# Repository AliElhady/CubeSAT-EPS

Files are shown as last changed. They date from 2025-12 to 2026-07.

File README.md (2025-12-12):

# CubeSAT-EPS
CubeSat Electrical Power System (EPS)

This project is a custom Electrical Power System for a CubeSat-class satellite, designed from scratch around a 2-cell Li-ion battery pack, solar input, and an STM32G474 microcontroller for smart power management and telemetry.

The EPS handles everything from harvesting solar energy, to charging and protecting the battery, to distributing clean, regulated rails to the rest of the satellite and streaming live power data to a ground station over LoRa.

Key Features

⚡ Solar Energy Harvesting & Battery Charging

MPPT-based solar charger (BQ24650 class) for 2S Li-ion pack
Supports simultaneous battery charging and system load powering
Automatic priority: uses solar power when available, falls back to battery when not

🔋 Battery Management & Protection

2-cell Li-ion battery pack with BMS for over-charge, over-discharge and over-current protection
Ideal-diode & reverse-polarity MOSFET circuitry on the battery input
TVS + LC filtering on critical power rails

📏 Power Monitoring & Telemetry

Multiple INA226 current/voltage monitors on battery, solar input, and main rails
Real-time telemetry sent via DL-SX1278PA LoRa module to a ground station
Designed for logging battery voltage, current, power, and solar harvesting performance

🧠 Control & Housekeeping

STM32G474RE microcontroller for EPS control, data acquisition, and LoRa communication
5 V and 3.3 V regulated rails for payload, OBC, and communication subsystems
Fault monitoring hooks for future safe-mode / load-shedding logic

🛠️ Hardware-Focused Design

KiCad-based 4-layer PCB (EPS + LoRa + sensing on a single board)
U.FL RF connector with optional π-network pads for antenna matching
Designed as a teaching/learning platform for small-sat power electronics

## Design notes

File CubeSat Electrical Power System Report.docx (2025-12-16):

CubeSat Electrical Power System (EPS) – Project Report

Ali Elhady

Gleb Matcegora

Aaron Vinod

Ilia State University

U841-Senior Design Project Conception

10/28/2025

Project Overview

Our senior design project focuses on the development of a CubeSat Electrical Power System (EPS) — a miniature version of the subsystem responsible for power generation, storage, and distribution in real satellites. The main goal is to design and implement a functional prototype that demonstrates how solar energy can be harvested, stored in rechargeable batteries, and efficiently supplied to different onboard subsystems. This mock-up will serve as a realistic educational model of a CubeSat’s power subsystem, showcasing the complete energy flow and power management principles used in small satellite missions.

The EPS prototype will consist of solar panels, a BQ24650 MPPT charge controller for optimal solar charging, 2S Li-ion battery packs for energy storage, and DC-DC converters (AP63203WU-7) providing 5 V and 3.3 V regulated outputs for different subsystems. Current and voltage monitoring sensors (INA219/INA226) will track power usage and battery status, while an STM32 microcontroller will manage data collection, control logic, and operational mode switching. The entire system will be designed and integrated using KiCad, with an emphasis on efficiency, compactness, and clarity of power flow.

At the current stage, our work primarily involves selecting compatible components, designing efficient circuit schematics, and developing the initial PCB layout. As the project progresses, we are also open to exploring additional features that could enhance the realism and functionality of the system — such as integrating an antenna for basic radio-frequency transmission, incorporating a reaction wheel for attitude control demonstrations, or implementing a low-power mode to optimize energy usage under limited sunlight conditions. These possibilities will be discussed with our supervisor before final implementation to ensure feasibility within the project’s scope.

Ultimately, the project aims to deliver a working educational prototype that demonstrates efficient energy harvesting, battery management, and power distribution in a CubeSat-like environment. This model will serve as a valuable learning platform for understanding how real satellite systems manage and distribute electrical power in space applications.

Current Progress

So far, our team has been in the brainstorming and component selection phase. We are carefully evaluating components that can work efficiently together within the limitations of size, power, and cost. This includes choosing buck converters (AP63203WU-7) for voltage regulation, Li-ion batteries for energy storage, solar panels for power input, and INA219/INA226 sensors for current and voltage monitoring. The schematic design is underway, with the circuit being transferred to KiCad for layout and preliminary simulation. This step helps visualize interconnections, verify electrical compatibility, and ensure the design remains practical for future fabrication and testing.

Future Work & Improvements

In the next phase, our team will focus on the following improvements and extensions:

1. PCB Fabrication & Testing: Finalize the KiCad design and manufacture a functional PCB prototype for laboratory testing.

2. System Optimization: Improve converter efficiency and implement dynamic power distribution using STM32 logic.

3. Telemetry & Data Logging: Add communication modules to monitor system voltage, current, and temperature remotely.

4. Reaction Wheel Integration: Design and test a reaction wheel subsystem to simulate CubeSat attitude control.

5. Final Model Assembly: Combine all modules into a compact, educational CubeSat mock-up that visually demonstrates power flow and control.

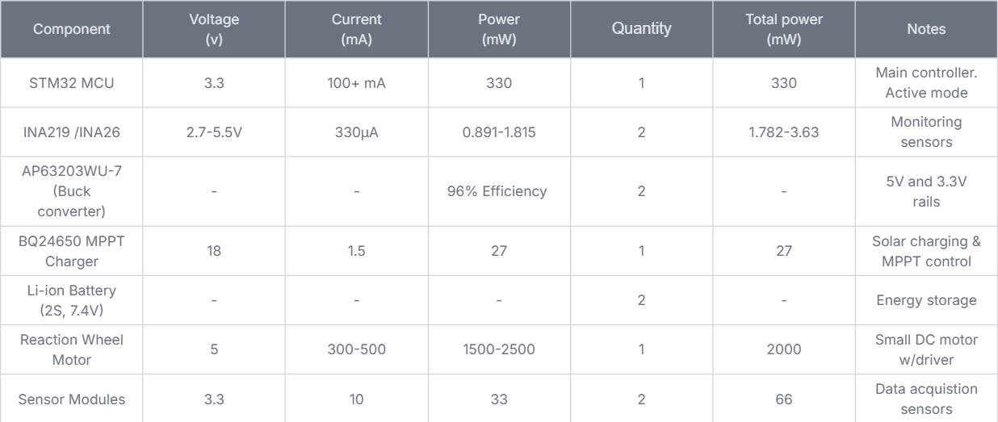
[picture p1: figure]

Power Consumption Analysis

Power Sources and Generation

Source | Voltage | Voc | Current (A) | Power (W) | Notes
Solar Panel (20-25W) | 12Nominal / 17Vmp | 21V | 1.2-1.5 | ~20-25 | Main power through mppt requires 21voc according to datasheet.
Battery Pack (2S Li-Ion, 2500 mAh or higher) | 7.4-8.4 | - | 2-4 | ~15-25 | Backup power and energy buffer

Estimated Battery Runtime

For two 3.7 V, 2500 mAh Li-ion batteries in series (≈18.5 Wh total): Idle / Light Load (0.5 W): ~37 hours With Reaction Wheel (2.5 W): ~7 hours Continuous operation during sunlight: Practically indefinite (solar-powered via MPPT).

Expected Outcomes

By the end of the project, we expect to achieve the following outcomes:

1. Functional EPS Prototype
  - A fully operational miniature Electrical Power System that can successfully harvest solar energy, charge Li-ion batteries, and regulate power output to multiple subsystems (5 V and 3.3 V rails).
  - Demonstration of real-time energy flow between solar panels, batteries, and loads.
2. Efficient Power Management
  - Implementation of a Maximum Power Point Tracking (MPPT) algorithm through the BQ24650 to maximize solar charging efficiency.
  - Stable and efficient voltage regulation using DC-DC converters (AP63203WU-7) under variable load conditions.
3. Monitoring and Control System
  - Integration of INA219/INA226 sensors with an STM32 microcontroller to measure voltage, current, and battery state-of-charge.
  - Data logging or display capability to visualize system behaviour and performance during operation.
4. Educational Demonstration Model
  - A physical prototype that visually and practically represents how a real CubeSat manages its electrical power.
  - Useful as a training and demonstration tool for future students or research in satellite power systems.
5. Design and Documentation Deliverables
  - Complete circuit schematics, PCB layout (KiCad), and a Bill of Materials (BOM).
  - A detailed project report outlining system design, operation, and performance evaluation.
6. Future Expansion Possibilities
  - While not finalized, the project may explore the possibility of integrating advanced features such as a radio-frequency antenna, a reaction wheel for orientation control, and a low-power operating mode for improved energy conservation.
  - These features, if approved, would make the prototype more representative of a complete CubeSat platform.

Summary

In summary, this project represents a comprehensive effort to design, simulate, and implement a miniature CubeSat Electrical Power System that models the real-world behavior of satellite energy management. Through careful component selection, circuit design, and microcontroller integration, the team aims to demonstrate how solar energy can be effectively captured, stored, and distributed in small-scale space systems.
The prototype will not only highlight the technical principles behind EPS design but will also serve as an educational and research tool for understanding energy flow, system reliability, and future advancements in CubeSat technology. By potentially incorporating communication and orientation features in later stages.

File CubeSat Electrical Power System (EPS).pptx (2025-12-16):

## CubeSat Electrical Power System (EPS)

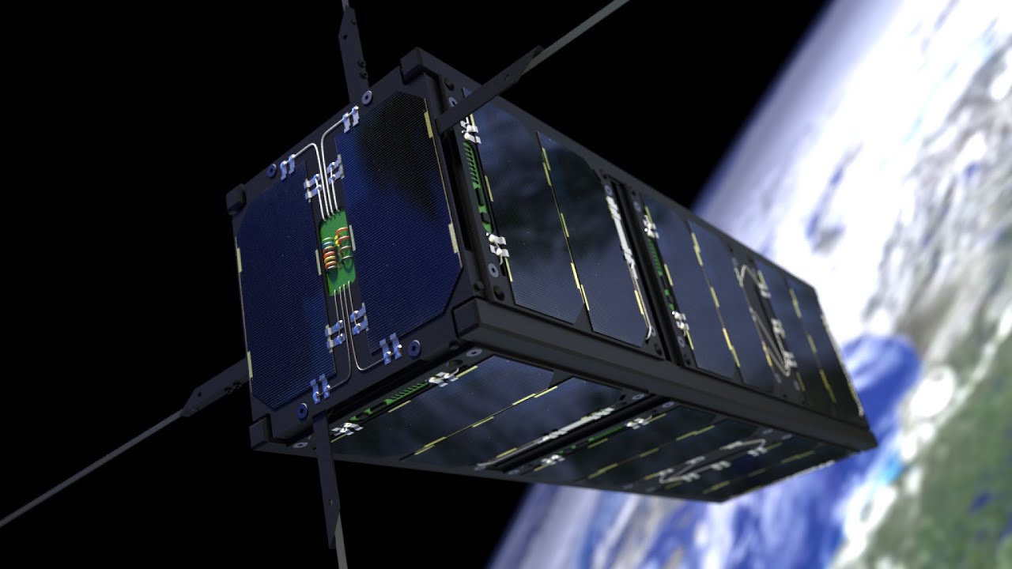
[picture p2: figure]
Picture background

## Introduction

- CubeSat Electrical Power System (EPS) manages the power collection and distribution in the satellite with an integrated Battery Management System (BMS). The EPS stores generated energy in onboard lithium-ion batteries. Some of the EPS features are:
Power generation. Solar cells, bypass diodes, and energy harvesting.
Power safety and fault protection. Polyfuses, resettable fuses, TVS diodes, Schottky diodes, isolation relays, and a watchdog timer IC.
Connectors and wiring. Board-to-board connectors, PCB terminals, a power distribution board, harnessing, connectors, screw terminals

## Project objective:

- To create a demonstration model of a CubeSat EPS to study the principles of operation of small satellite power supply systems.

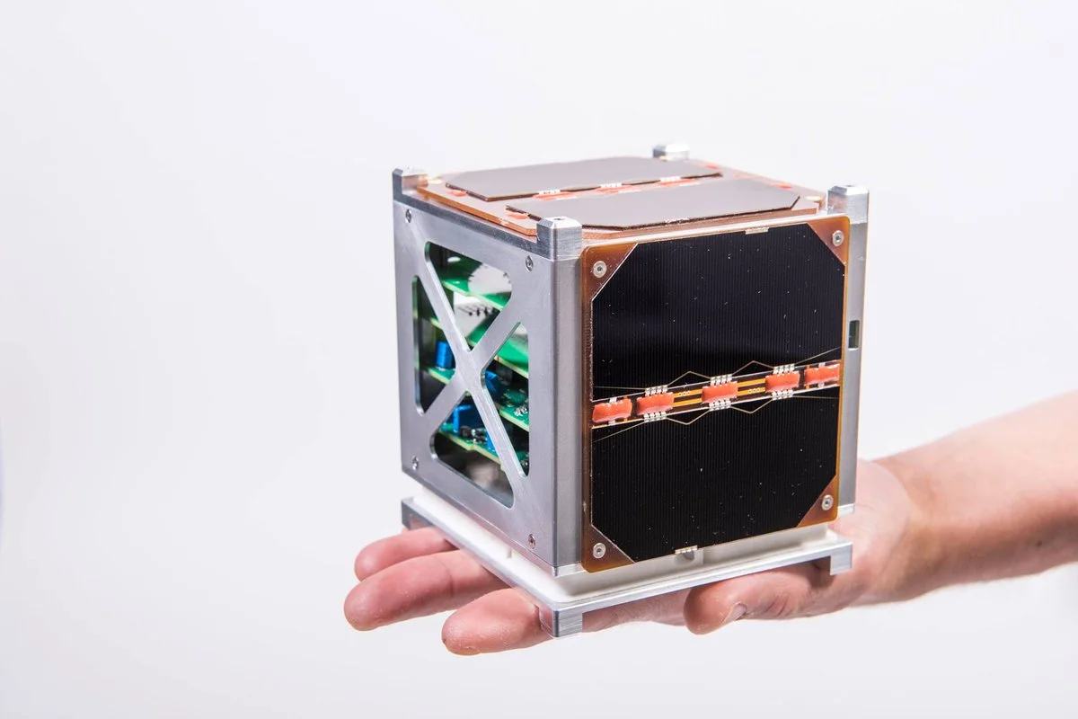
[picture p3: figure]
Picture background

## Relevance

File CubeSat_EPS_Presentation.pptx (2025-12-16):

## CubeSat Electrical Power System (EPS)

- Objective:
- To design and implement a miniature satellite power management system that simulates energy generation, storage, and distribution.
- Team Members: [Add Names]
- Supervisor: [Add Name]

## Project Overview

- CubeSats require a reliable Electrical Power System (EPS) to:
- - Generate power (via solar panels)
- - Store energy (in batteries)
- - Distribute power (through converters and controllers)
- Our mock-up replicates this using solar panel imitation, STM32 controller, and telemetry for monitoring.

## System Components

- 1. Solar Panels / Simulators
- 2. Battery (Li-ion / Li-Po) with BMS
- 3. DC-DC Converters for 5V and 3.3V
- 4. STM32 Microcontroller for control and monitoring
- 5. Load Simulation using LEDs, fans, or small modules

## System Architecture

- Power Flow:
- Solar Panel → Charge Controller → Battery → DC-DC Converters → Loads
- Control Flow:
- STM32 monitors current, voltage, state of charge, and temperature, controlling load switching & safety.

## Circuit Design

- Main Sections:
- - Charging Stage: Solar panel + TP4056 charge controller ( for battery charging )
- - Storage Stage: Battery + BMS
- - Conversion Stage: DC-DC converters
- - Measurement: Voltage dividers + INA219 or ACS712 current sensors

## STM32 Controller Functions

- - Read battery voltage and current through ADC
- - Estimate State of Charge (SOC)
- - Manage charging/discharging
- - Cut off power when voltage is too low
- - Communicate telemetry data via UART/Bluetooth

## Telemetry and Data Visualization

- Purpose: To monitor satellite power health in real time.
- Features:
- - Display battery voltage, current, and temperature
- - Live graphing of charge/discharge cycles
- - Data transmission via UART or Bluetooth

## Load Simulation

- LEDs, fans, or motors simulate subsystems.
- Controlled by MOSFETs via STM32.
- Goal: Demonstrate realistic power distribution.

## Software & Firmware Design

- Firmware (STM32):
- - ADC readings
- - Power mode logic
- - UART/Bluetooth communication
- PC Interface:
- - Serial visualization
- - Graphs and system alerts

## Expected Results

- - Stable 5V and 3.3V outputs
- - Accurate telemetry reporting
- - Automatic charge/discharge control
- - Realistic simulation of CubeSat EPS

## Future Improvements

- - Integrate MPPT
- - Add temperature compensation
- - Implement LoRa telemetry
- - Fabricate a PCB prototype

## Conclusion

- The CubeSat EPS mock-up demonstrates:
- - Efficient power management
- - Safe battery operation
- - Real-time telemetry & visualization
- Outcome: Functional miniature model of real CubeSat EPS.

## References

- - CubeSat Design Specification (Cal Poly SLO)
- - STM32 Datasheet & HAL Documentation
- - TP4056 & INA219 Datasheets
- - Research papers on CubeSat EPS design

## Q&A

- Thank you!
- Questions?

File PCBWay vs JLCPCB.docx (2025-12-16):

PCB manufacturing research – JLCPCB vs PCBWay

This report compares PCB fabrication options between JLCPCB and PCBWay for the CubeSat Electrical Power System (EPS) prototype. The goal is to identify a reliable and cost-effective manufacturer while maintaining high-quality electrical and mechanical performance.

Parameter | JLCpcb | PCBway | Notes
Base Price (4 Layers) | 7$ | 23$ | JLCPCB offers frequent 4-layer promotions for small prototypes
Base Price (2 Layers) | More expensive (via tenting adds ~20$) | Cheaper but fewer options | JLCPCB charges extra for via tenting on 2-layer boards
Size | 100 × 100 mm | 100 × 100 mm | Standard prototype board size
Quantity | 5 pcs | 5 pcs | Small prototype batch
Thickness | 1.6 mm | 1.6 mm | Standard PCB thickness
Copper weight | 1 oz (inner & outer) | 1 oz | Sufficient for low-to-medium current levels
Min Trace width | 3.5 mil (0.09 mm) | 4 mil (0.10 mm) | Higher precision allows denser routing
Solder mask | Green (default) | Green (default) | Cheapest and easiest to inspect visually
Surface Finish | ENIG (nickel and gold plated) | HASL or ENIG | ENIG is preferred for EPS: better thermal, corrosion, and electrical characteristics
Via covering | Tented (default on 4-layer | Tented or Plugged (extra cost) | 4-layer tenting included by default at JLCPCB
Build time | Standard 3-4 days | Standard 3-4 days | Expedited builds available but increase cost

Conclusion:

After careful comparison, JLCPCB is the preferred manufacturer for the CubeSat EPS prototype, it offers 4-layers PCB’s for only 7$, compared to 23$ at PCBway. JLCPCB included tented vias by default and provides reliable ENIG surface finishing, ensuring precision, corrosion resistance and superior solderability. Ideal for circuits involving

ADC readings, current monitoring and fine-pitch SMDs. PCBWay, while reputable, is significantly more expensive for equivalent builds.

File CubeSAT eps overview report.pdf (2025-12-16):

# CubeSat Electrical Power System (EPS) – Project Report

## Project Overview

Our senior design project focuses on the development of a CubeSat Electrical Power System (EPS) — a miniature version of the system that manages power generation, storage, and distribution in real satellites. The main goal is to design and implement a functional prototype that demonstrates how solar energy can be harvested, stored in rechargeable batteries, and supplied to different onboard subsystems efficiently. This mock-up will serve as a realistic educational model of a CubeSat’s power subsystem, showcasing energy flow and system management principles.

## Current Progress

So far, our team has been in the brainstorming and component selection phase. We are carefully evaluating components that can work efficiently together within the limitations of size, power, and cost. This includes choosing buck converters (AP63203WU-7) for voltage regulation, Li-ion batteries for energy storage, solar panels for power input, and INA219/INA226 sensors for current and voltage monitoring. We are also in the process of designing the circuit schematics and transferring them into KiCad for PCB layout and simulation. This step allows us to visualize the interconnections between components and determine the optimal design approach for reliability and efficiency.

## Future Plans

In the next stages, we plan to finalize the circuit design and proceed to PCB fabrication and testing. Once the power system is stable and verified, we aim to expand the project by integrating a reaction wheel system. This addition would allow us to simulate the attitude control of a real CubeSat, turning the project from a simple EPS demonstration into a complete, functional mock satellite model.

## Power Consumption Analysis

Component | Voltage (V) Current (mA)Power (mW) | Quantity Total Power (mW) | Notes
STM32 MCU | 3.3 | 100+ mA | 330 | 1 | 330 | Main controller; active mode
INA219 / INA226 | 3.3 | 330µA | 990 | | 6.6 | Monitoring sensors
| | — ≈96% efficiency | | 2 | — | 5 V and 3.3 V rails
AP63203WU-7 (Buck Converter)
—
BQ24650 MPPT Charger 12 | 15µA | 0.18 | 1 | 200 Solar charging & MPPT control
Li-Ion Battery (2S, 7.4V) | — | — | — | 2 | — | Energy storage
Reaction Wheel Motor | 5 | 300–500 | 1500–2500 | 1 | 2000 | Small DC motor w/ driver
Sensor Modules | 3.3 | 10 | 33 | 2 | 66 | Data acquisition sensors

## Power Sources and Generation

Source | Nominal Voltage | Current (A) | Power (W) | Notes
Solar Panel (25 W) | 12 | 2.08 | 25 | Main power through MPPT
Battery Pack (2S Li-Ion, 2500 mAh) | 7.4 | — | 18.5 Wh | Backup power and energy buffer

## Estimated Battery Runtime

For two 3.7 V, 2500 mAh Li-ion batteries in series (≈18.5 Wh total): Idle / Light Load (0.5 W): ~37 hours With Reaction Wheel (2.5 W): ~7 hours Continuous operation during sunlight: Practically indefinite (solar-powered via MPPT).

## Summary

The current EPS design efficiently supports the CubeSat prototype’s electronics with low power draw. The 5 V and 3.3 V rails provide flexibility for digital and electromechanical loads. The solar + battery hybrid setup ensures continuous operation even in low light. The addition of the reaction wheel will increase power demand, highlighting the need for optimized energy management and battery capacity.

## Future Work & Improvements

In the next phase, our team will focus on the following improvements and extensions: 1. PCB Fabrication & Testing: Finalize the KiCad design and manufacture a functional PCB prototype for laboratory testing. 2. System Optimization: Improve converter efficiency and implement dynamic power distribution using STM32 logic. 3. Telemetry & Data Logging: Add communication modules to monitor system voltage, current, and temperature remotely. 4. Reaction Wheel Integration: Design and test a reaction wheel subsystem to simulate CubeSat attitude control. 5. Final Model Assembly: Combine all modules into a compact, educational CubeSat mock-up that visually demonstrates power flow and control.

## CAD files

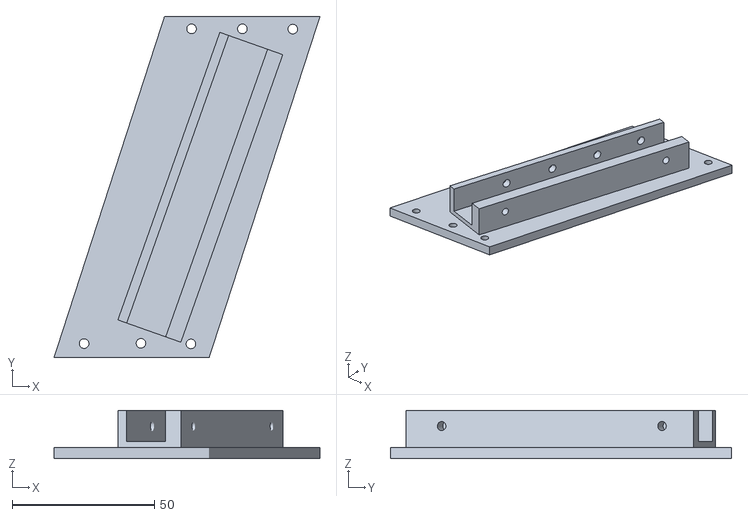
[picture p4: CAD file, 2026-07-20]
Mechanical Design/solar side1 (1).stl
93.6 x 120.0 x 17.0

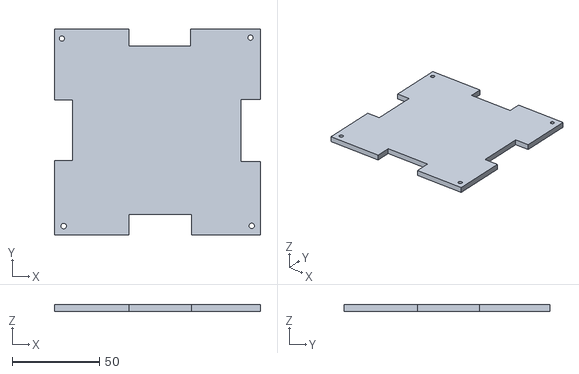
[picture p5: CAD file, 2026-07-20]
Mechanical Design/battery .stl
117.9 x 118.0 x 4.00

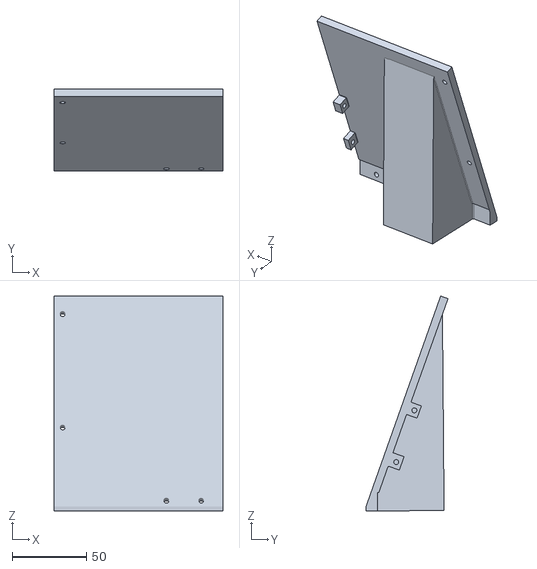
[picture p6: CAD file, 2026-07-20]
Mechanical Design/solar stand 1 (1).stl
113.8 x 55.4 x 145.1

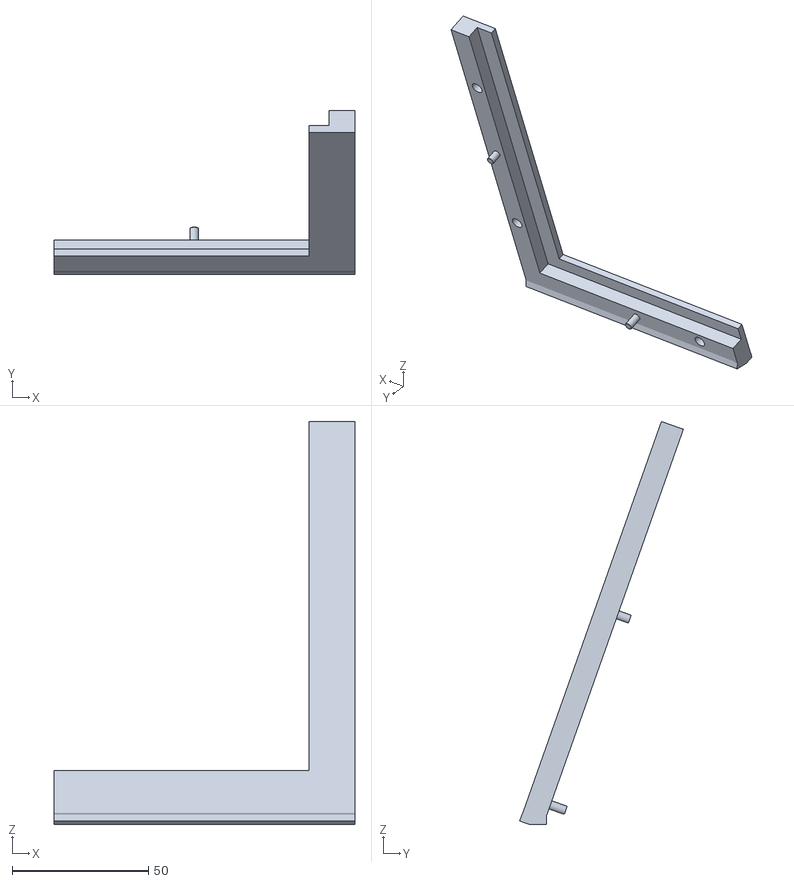
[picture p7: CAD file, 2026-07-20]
Mechanical Design/solar frame 3 (1).stl
110.4 x 60.2 x 148.0

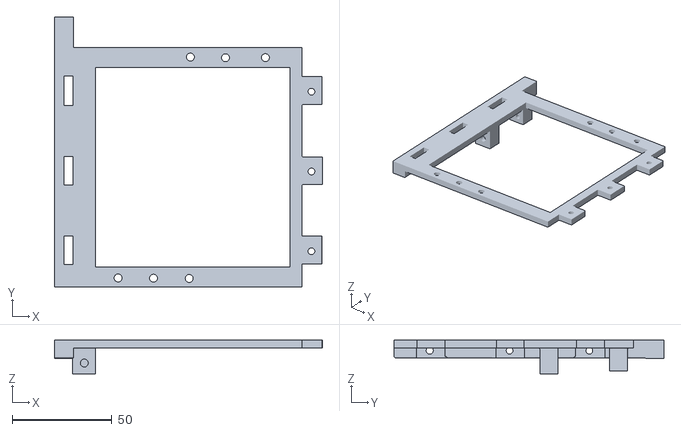
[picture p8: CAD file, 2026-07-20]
Mechanical Design/cubesat 4.stl
134.3 x 135.1 x 17.0

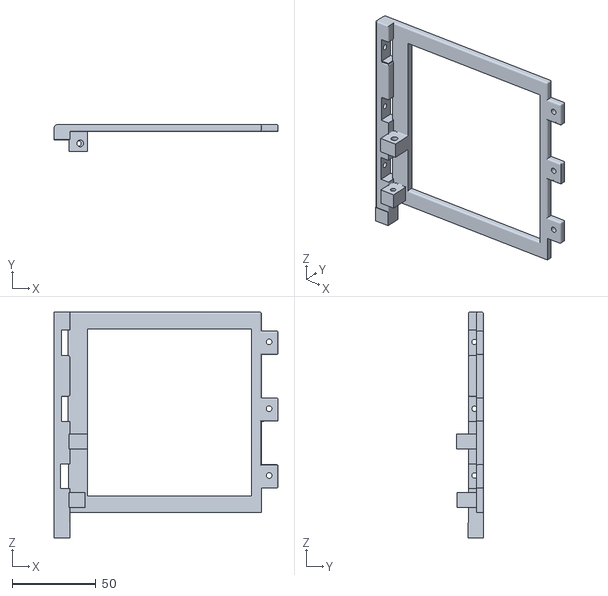
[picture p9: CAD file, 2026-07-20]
Mechanical Design/cubesat5.stl
134.1 x 16.0 x 135.1

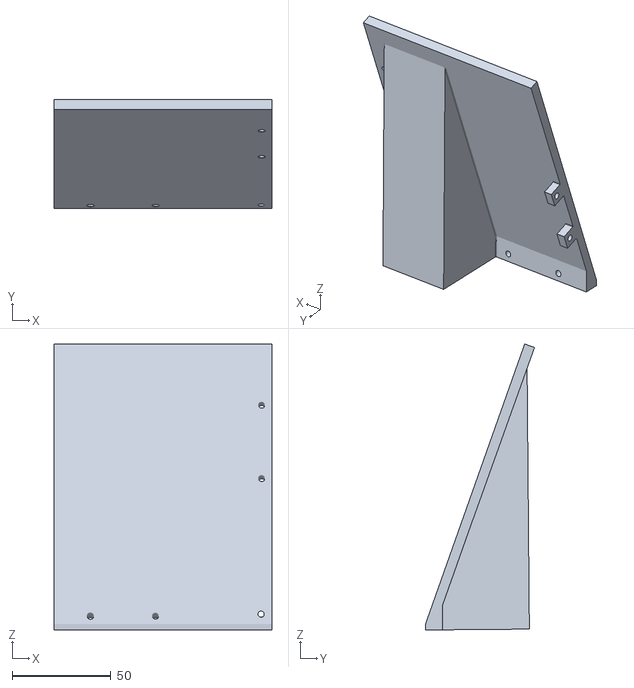
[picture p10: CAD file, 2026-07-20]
Mechanical Design/solar stand 3 (1).stl
110.4 x 55.3 x 145.1

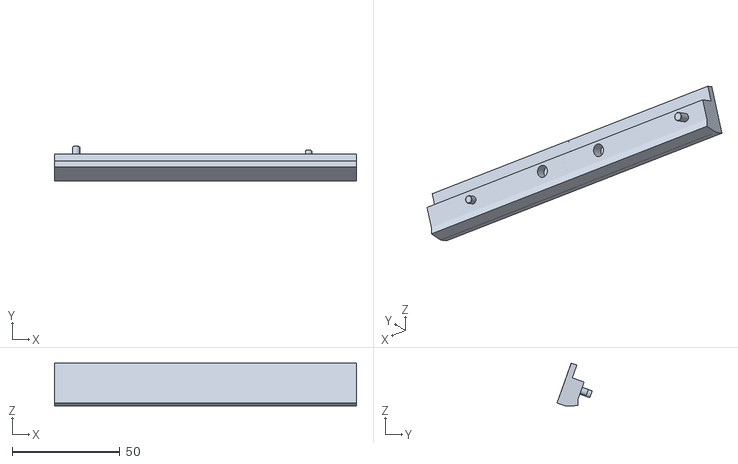
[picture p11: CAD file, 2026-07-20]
Mechanical Design/solar frame 2 (1).stl
140.4 x 16.4 x 19.9

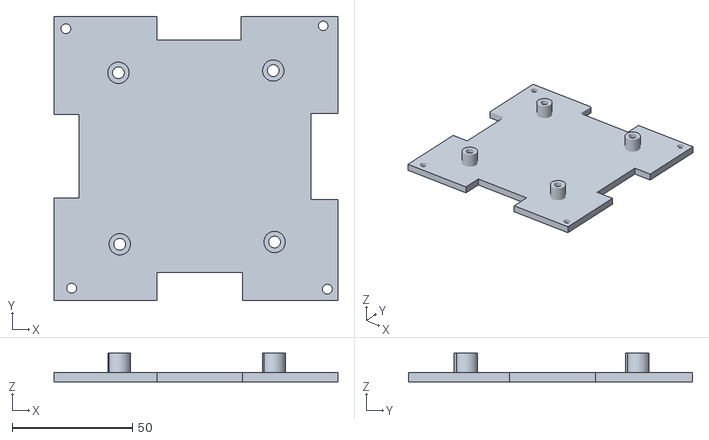
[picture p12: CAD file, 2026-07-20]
Mechanical Design/pcbstand.stl
117.9 x 118.0 x 12.0

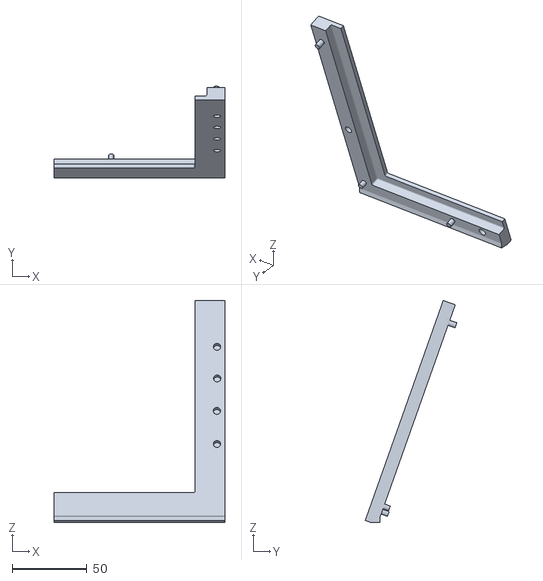
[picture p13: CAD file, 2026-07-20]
Mechanical Design/solar frame 1 left (1).stl
113.8 x 61.2 x 148.1

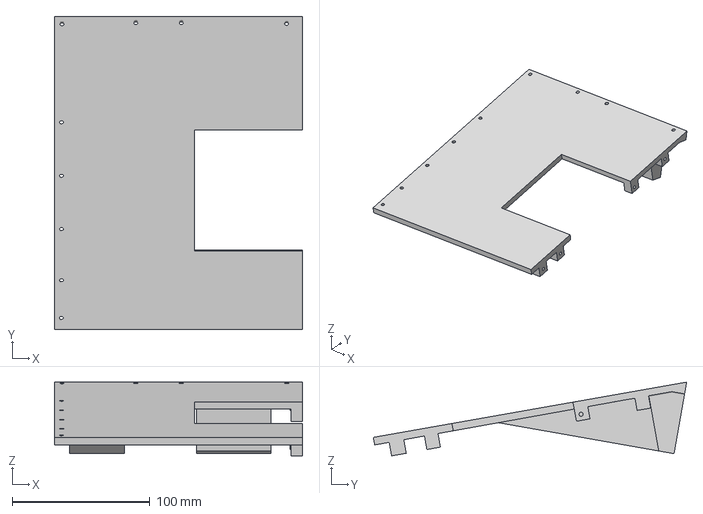
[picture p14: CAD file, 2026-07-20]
Mechanical Design/solar stand right 1 (1).3mf
179.9 x 227.3 x 53.5 mm

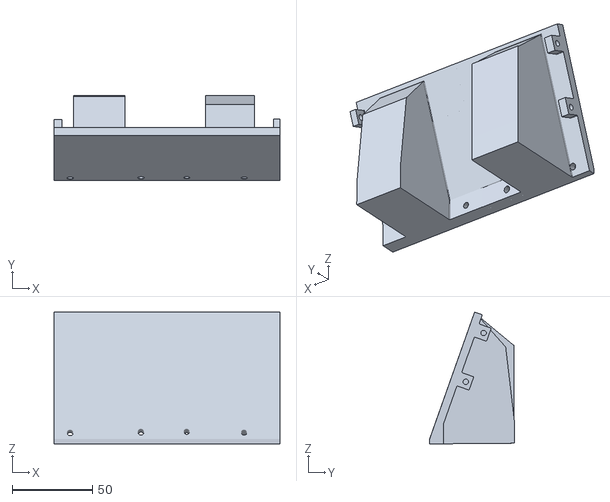
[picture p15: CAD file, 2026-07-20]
Mechanical Design/solar stand 2 (1) (1).stl
140.4 x 52.8 x 82.0

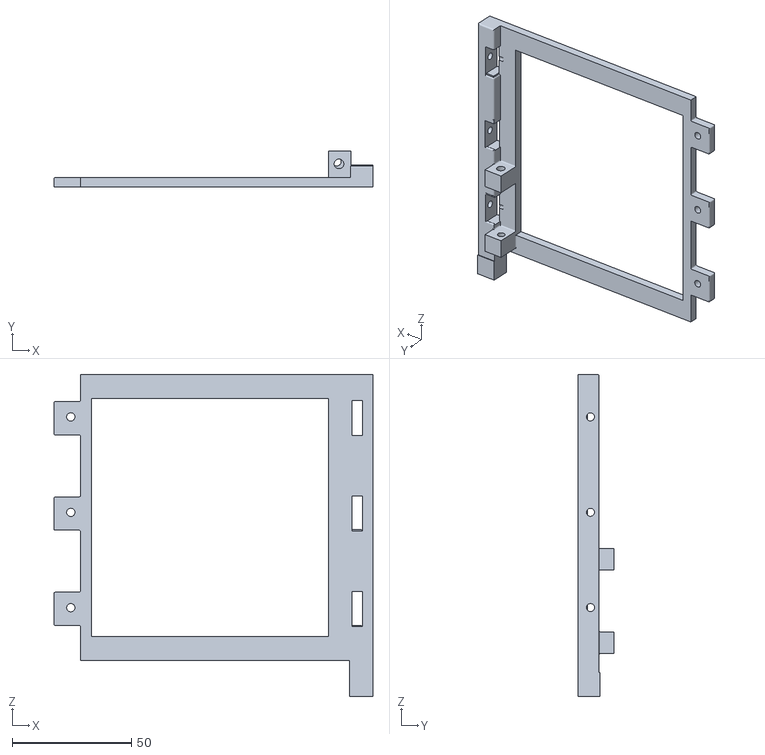
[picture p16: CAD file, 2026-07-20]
Mechanical Design/cubesat 3.stl
133.8 x 15.3 x 135.1

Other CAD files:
Mechanical Design/solar side 2 (1).stl
Mechanical Design/solar stand 1 left (1).stl
Mechanical Design/solar stand 3 left (1).stl
Mechanical Design/solar frame 1 (1).stl
Mechanical Design/solar stand 2 left (1).stl
Mechanical Design/cubesat 6.stl

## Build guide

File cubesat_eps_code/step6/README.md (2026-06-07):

# Шаг 6 — Telemetry: UART через DMA (финальная сборка)

## Файлы
- `main.c`            — точка входа
- `eps_soc.c/h`       — расчёт SOC
- `eps_fsm.c/h`       — машина состояний
- `eps_gpio.c/h`      — управление нагрузками
- `eps_flash.c/h`     — Flash persistence
- `eps_telemetry.c/h` — телеметрия UART

## Что добавилось
Передача по DMA — MCU не блокируется во время отправки.
Два режима: ASCII (отладка) и бинарный 16-байт пакет (OBC).
Адаптивный интервал: 5 с в Normal, 10 с в LowPower, 30 с в Critical.
Telem_SendNow() в каждом Enter_X() — мгновенное уведомление при смене состояния.

## Что настроить в CubeMX
- USART1 + DMA (Memory to Peripheral) → терминал/наземная станция
- USART2 + DMA → OBC
- TIM6 период = 1000 мс → Telem_TickSecond()
- ВАЖНО: MX_DMA_Init() вызывать ДО MX_USART_Init()

## Режим вывода
Переключается одной строкой в eps_telemetry.c:
  #define TELEM_MODE_ASCII    ← отладка
  #define TELEM_MODE_BINARY   ← реальный полёт

## Критерий готовности
- Пакеты приходят каждые 5 с в Normal, 30 с в Critical
- При смене состояния — пакет немедленно
- Счётчик packet_id без пропусков на 100 пакетах
- DMA: FSM продолжает работать во время передачи

## Формат ASCII пакета
```
$EPS,042,NORMAL,78%,7.85V,8.12V,COLD,ch1=1,ch2=1,chg=1,up=3600
```

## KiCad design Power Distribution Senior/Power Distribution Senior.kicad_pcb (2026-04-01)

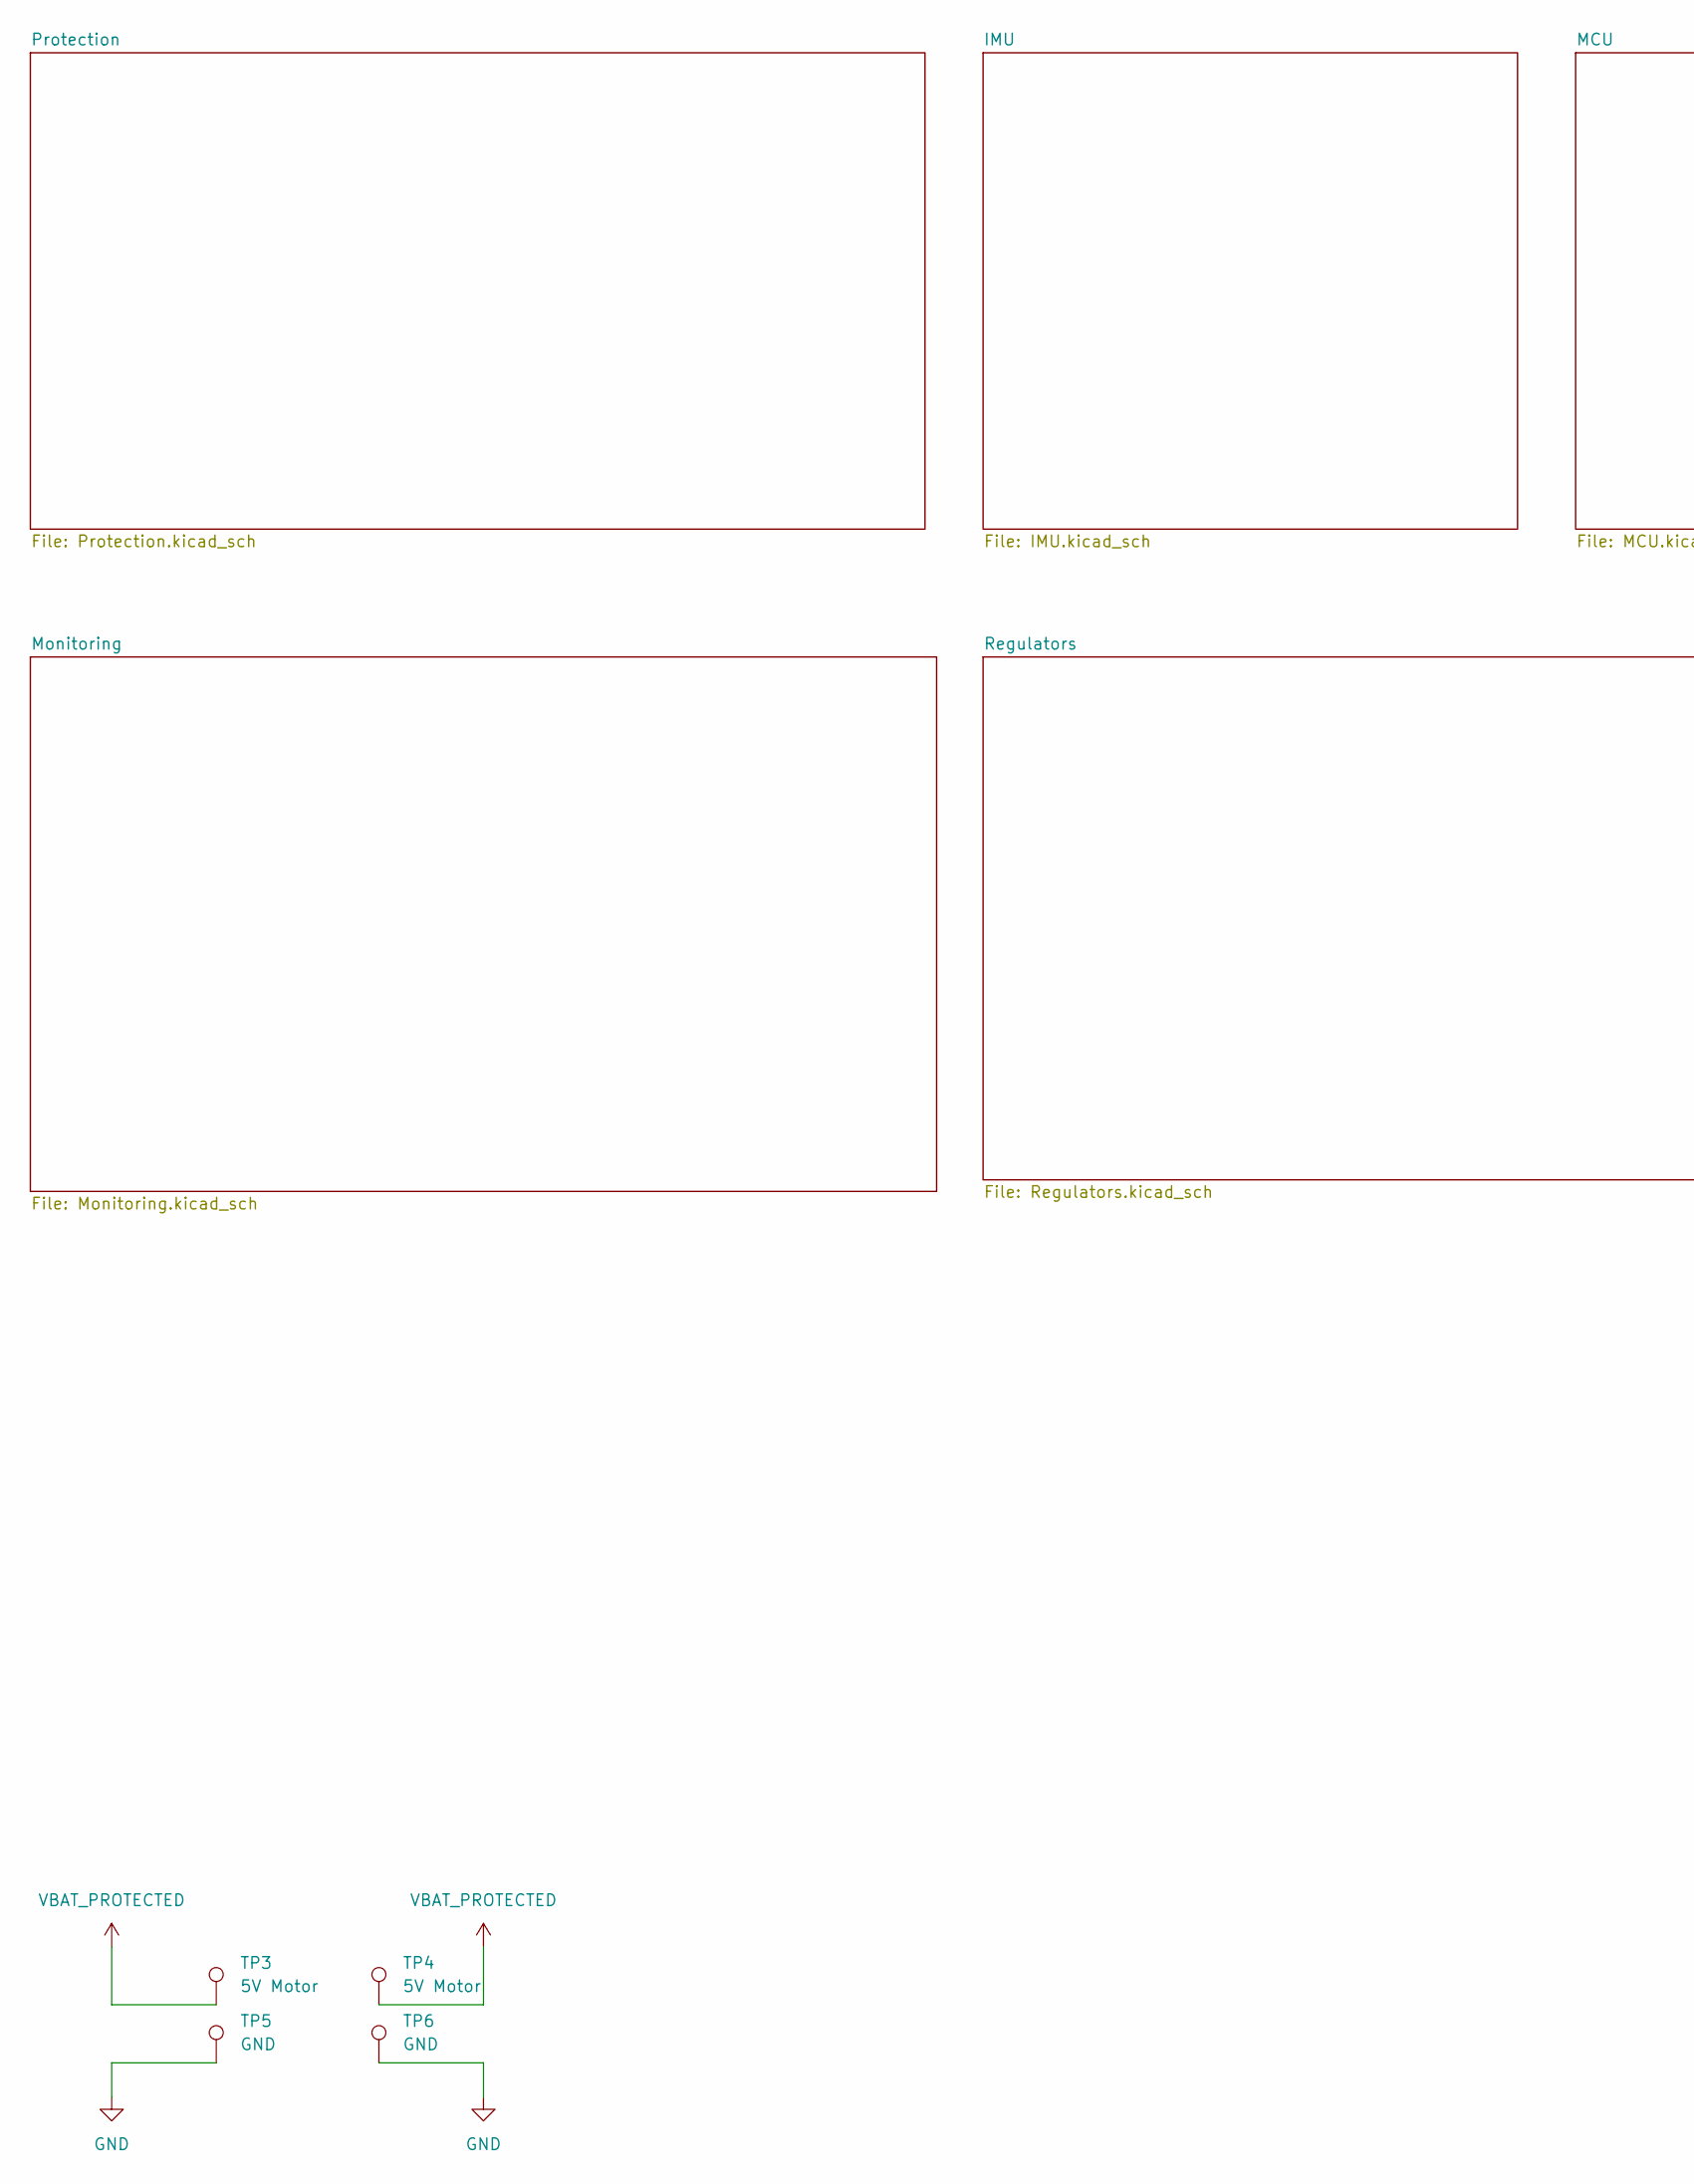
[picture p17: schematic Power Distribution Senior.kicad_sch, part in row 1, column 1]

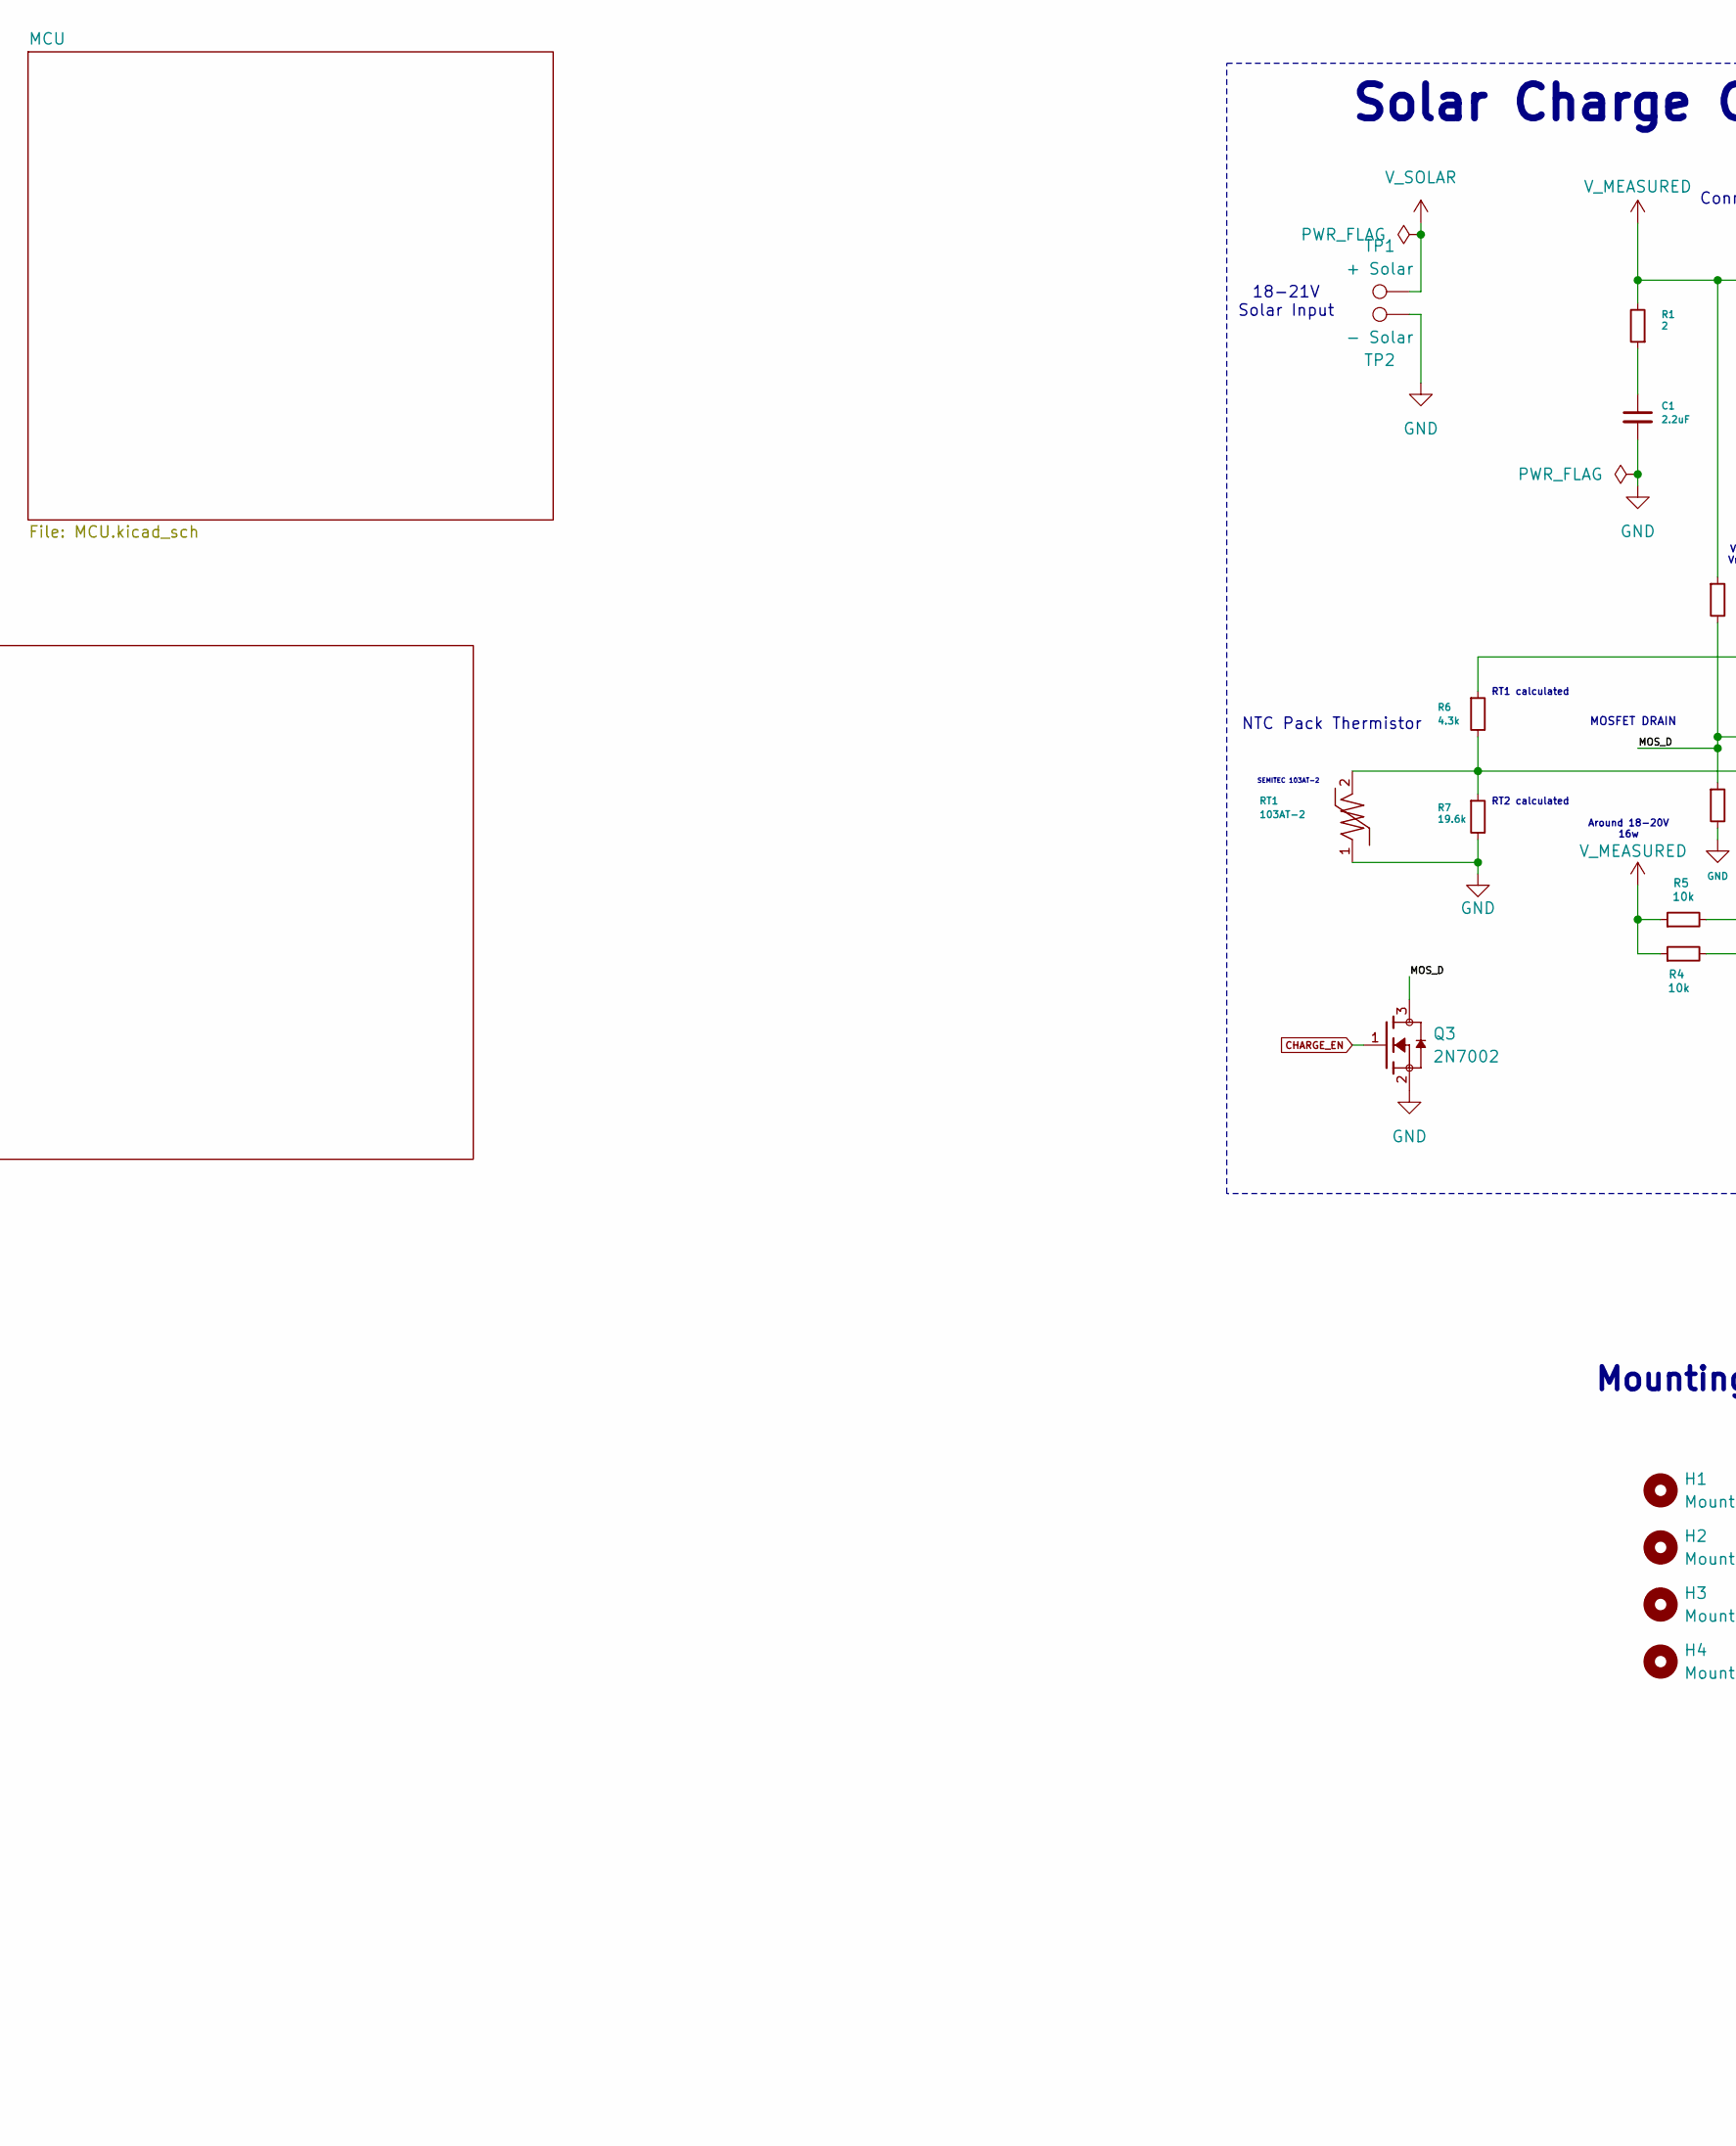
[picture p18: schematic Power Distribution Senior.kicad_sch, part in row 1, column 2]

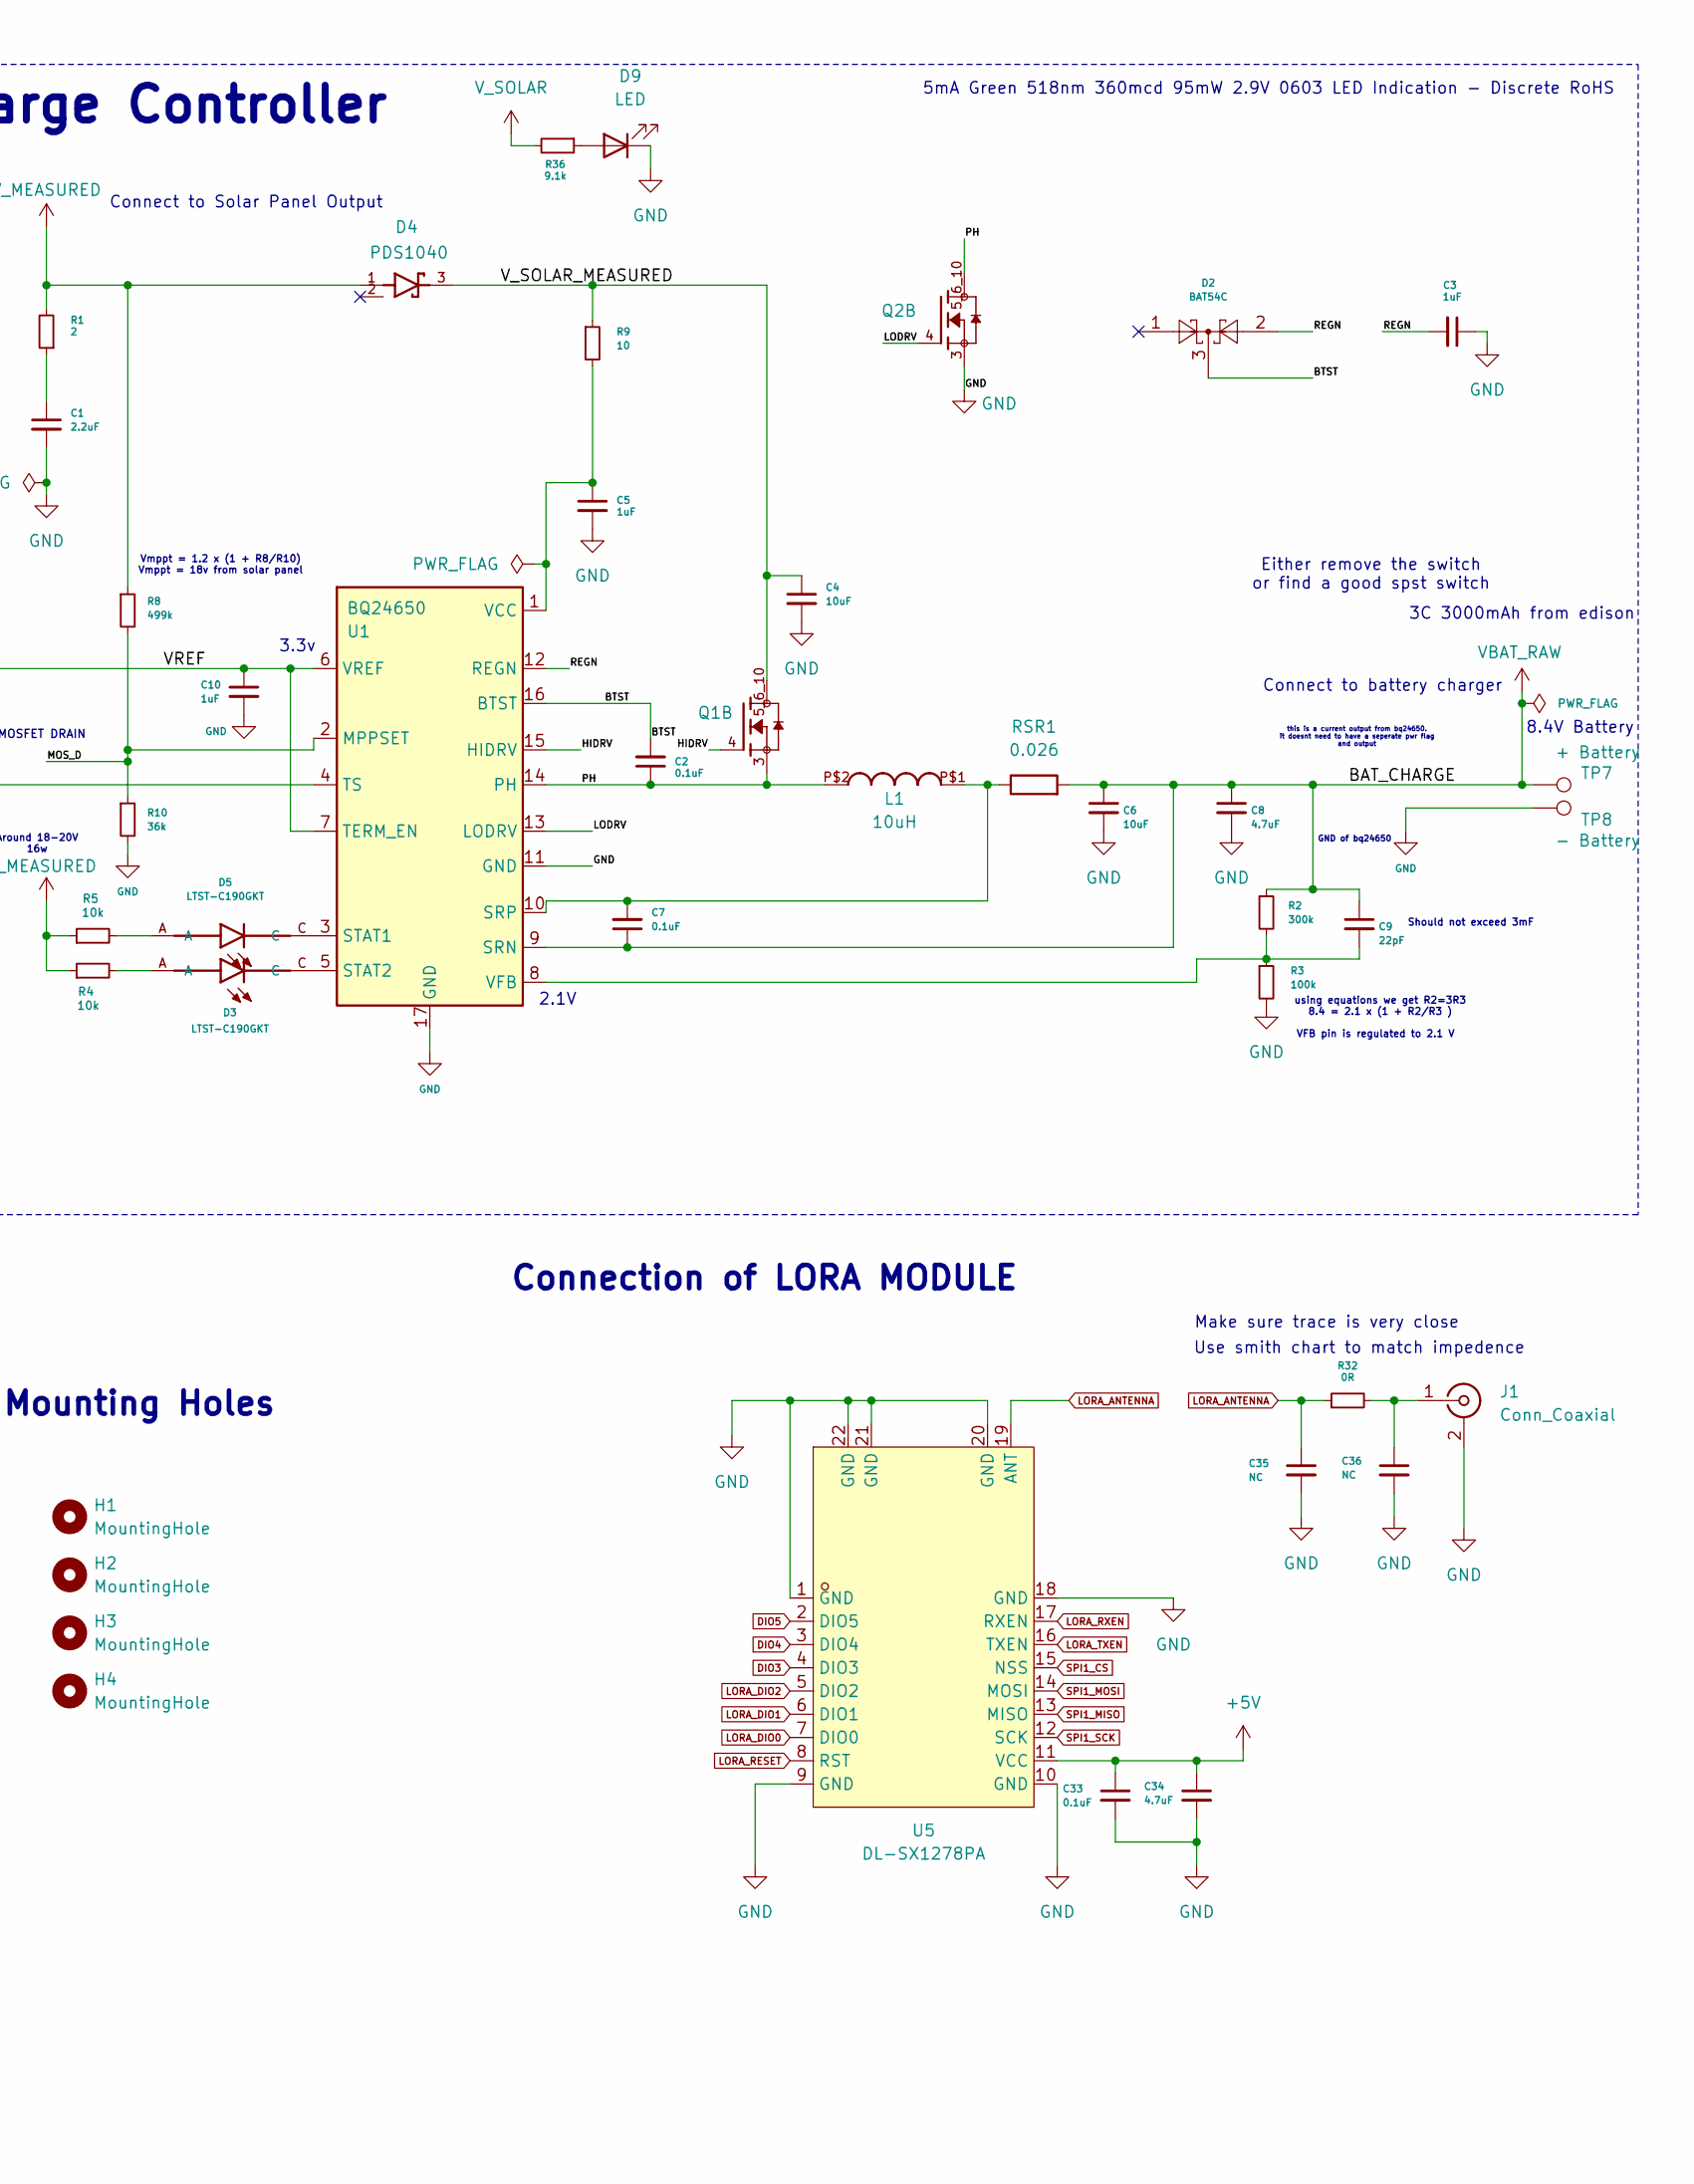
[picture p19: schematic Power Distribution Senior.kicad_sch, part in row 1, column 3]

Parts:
C1: 2.2uF; C_1206_3216Metric
C2, C7: 0.1uF; C_0805_2012Metric
C3, C5, C10: 1uF; C_0805_2012Metric
C4, C6: 10uF; C_0805_2012Metric
C8, C34: 4.7uF; C_1206_3216Metric
C9: 22pF; C_0402_1005Metric
C33: 0.1uF; C_0603_1608Metric
C35, C36: NC; C_0603_1608Metric
D2: BAT54C; SOT-23
D3, D5: LTST-C190GKT; LEDM1608X80
D4: PDS1040; DIO_PDS1040; PARTREV 13
D9: LED; LED_0603_1608Metric
H1, H2, H3, H4: MountingHole; MountingHole_3.2mm_M3_DIN965_Pad
J1: Conn_Coaxial; RF-SMD_FRF05002-JSS103M
L1: 10uH; 2525
Q1, Q2: SI7288DP-T1-GE3; TRANS_SI7288DP-T1-GE3; PARTREV A
Q3: 2N7002; TRANS_2N7002; PARTREV 2023-01-11
R1: 2; R_0805_2012Metric
R2: 300k; R_0402_1005Metric
R3: 100k; R_0402_1005Metric
R4, R5: 10k; R_0402_1005Metric
R6: 4.3k; R_0402_1005Metric
R7: 19.6k; R_0402_1005Metric
R8: 499k; R_0402_1005Metric
R9: 10; R_1206_3216Metric
R10: 36k; R_0402_1005Metric
R32: 0R; R_0805_2012Metric
R36: 9.1k; R_0805_2012Metric
RSR1: 0.026; R_2512_6332Metric
RT1: 103AT-2
TP1: + Solar; TestPoint_Pad_4.0x4.0mm
TP2: - Solar; TestPoint_Pad_4.0x4.0mm
TP3, TP4: 5V Motor; TestPoint_Pad_3.0x3.0mm
TP5, TP6: GND; TestPoint_Pad_3.0x3.0mm
TP7: + Battery; TestPoint_Pad_4.0x4.0mm
TP8: - Battery; TestPoint_Pad_4.0x4.0mm
U1: BQ24650; Texas_RVA_VQFN-16-1EP_3.5x3.5mm_P0.5mm_EP2.14x2.14mm_Therma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
U5: DL-SX1278PA; SMD-22_L37.0-W25.0-P2.54-LB; LCSC Part C3345217

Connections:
/BTST: C2.2, D2.3, U1.16 (BTST)
/HIDRV: Q1.4, U1.15 (HIDRV)
/LODRV: Q2.4, U1.13 (LODRV)
/MOS_D: Q3.3, R8.2, R10.1, U1.2 (MPPSET)
/PH: C2.1, L1.P$2, Q1.3, Q2.5_6_10, U1.14 (PH)
/REGN: C3.2, D2.2, U1.12 (REGN)
/VREF: C10.1, R6.1, U1.6 (VREF), U1.7 (TERM_EN)
/V_SOLAR_MEASURED: C4.1, D4.3, Q1.5_6_10, R9.1
CHARGE_EN: Q3.1; also elsewhere on the board
DIO3: U5.4 (DIO3)
DIO4: U5.3 (DIO4)
DIO5: U5.2 (DIO5)
GND: C1.2, C3.1, C4.2, C5.2, C6.2, C8.2, C10.2, C33.2, C34.2, C35.2, C36.2, D9.1 (K), J1.2 (Ext), Q2.3, Q3.2, R3.2, R7.2, R10.2, RT1.1, TP2.1, TP5.1, TP6.1, TP8.1, U1.11 (GND), U1.17 (GND), U5.1 (GND), U5.9 (GND), U5.10 (GND), U5.18 (GND), U5.20 (GND), U5.21 (GND), U5.22 (GND); also elsewhere on the board
INA226_VS: C33.1, C34.1, U5.11 (VCC); also elsewhere on the board
LORA_ANTENNA: C35.1, R32.1, U5.19 (ANT)
LORA_DIO0: U5.7 (DIO0); also elsewhere on the board
LORA_DIO1: U5.6 (DIO1); also elsewhere on the board
LORA_DIO2: U5.5 (DIO2); also elsewhere on the board
LORA_RESET: U5.8 (RST); also elsewhere on the board
LORA_RXEN: U5.17 (RXEN); also elsewhere on the board
LORA_TXEN: U5.16 (TXEN); also elsewhere on the board
unnamed: C1.1, R1.1
unnamed: D3.A, R4.2
unnamed: D5.A, R5.2
unnamed: D9.2 (A), R36.1
unnamed: C36.1, J1.1 (In), R32.2
unnamed: C7.2, L1.P$1, RSR1.1, U1.10 (SRP)
unnamed: D5.C, U1.3 (STAT1)
unnamed: D3.C, U1.5 (STAT2)
unnamed: R6.2, R7.1, RT1.2, U1.4 (TS)
unnamed: C5.1, R9.2, U1.1 (VCC)
unnamed: C9.2, R2.2, R3.1, U1.8 (VFB)
SPI1_CS: U5.15 (NSS); also elsewhere on the board
SPI1_MISO: U5.13 (MISO); also elsewhere on the board
SPI1_MOSI: U5.14 (MOSI); also elsewhere on the board
SPI1_SCK: U5.12 (SCK); also elsewhere on the board
VBAT_PROTECTED: TP3.1, TP4.1; also elsewhere on the board
VBAT_RAW: C6.1, C7.1, C8.1, C9.1, R2.1, RSR1.2, TP7.1, U1.9 (SRN); also elsewhere on the board
V_MEASURED: D4.1, R1.2, R4.1, R5.1, R8.1; also elsewhere on the board
V_SOLAR: R36.2, TP1.1; also elsewhere on the board

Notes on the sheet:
Solar Charge Controller
VFB pin is regulated to 2.1 V
Use smith chart to match impedence
this is a current output from bq24650. it doesnt need to have a seperate pwr flag and output
RT1 calculated
Around 18-20V 16w
Should not exceed 3mF
NTC Pack Thermistor
3C 3000mAh from edison
Vmppt = 1.2 x (1 + R8/R10) Vmppt = 18v from solar panel
GND of bq24650
RT2 calculated
Connect to Solar Panel Output
Connection of LORA MODULE
Connect to battery charger
3.3v
5mA Green 518nm 360mcd 95mW 2.9V 0603 LED Indication - Discrete RoHS
18-21V Solar Input
Mounting Holes
using equations we get R2=3R3 8.4 = 2.1 x (1 + R2/R3 )
MOSFET DRAIN
2.1V
Make sure trace is very close
SEMITEC 103AT-2
8.4V Battery
Either remove the switch or find a good spst switch

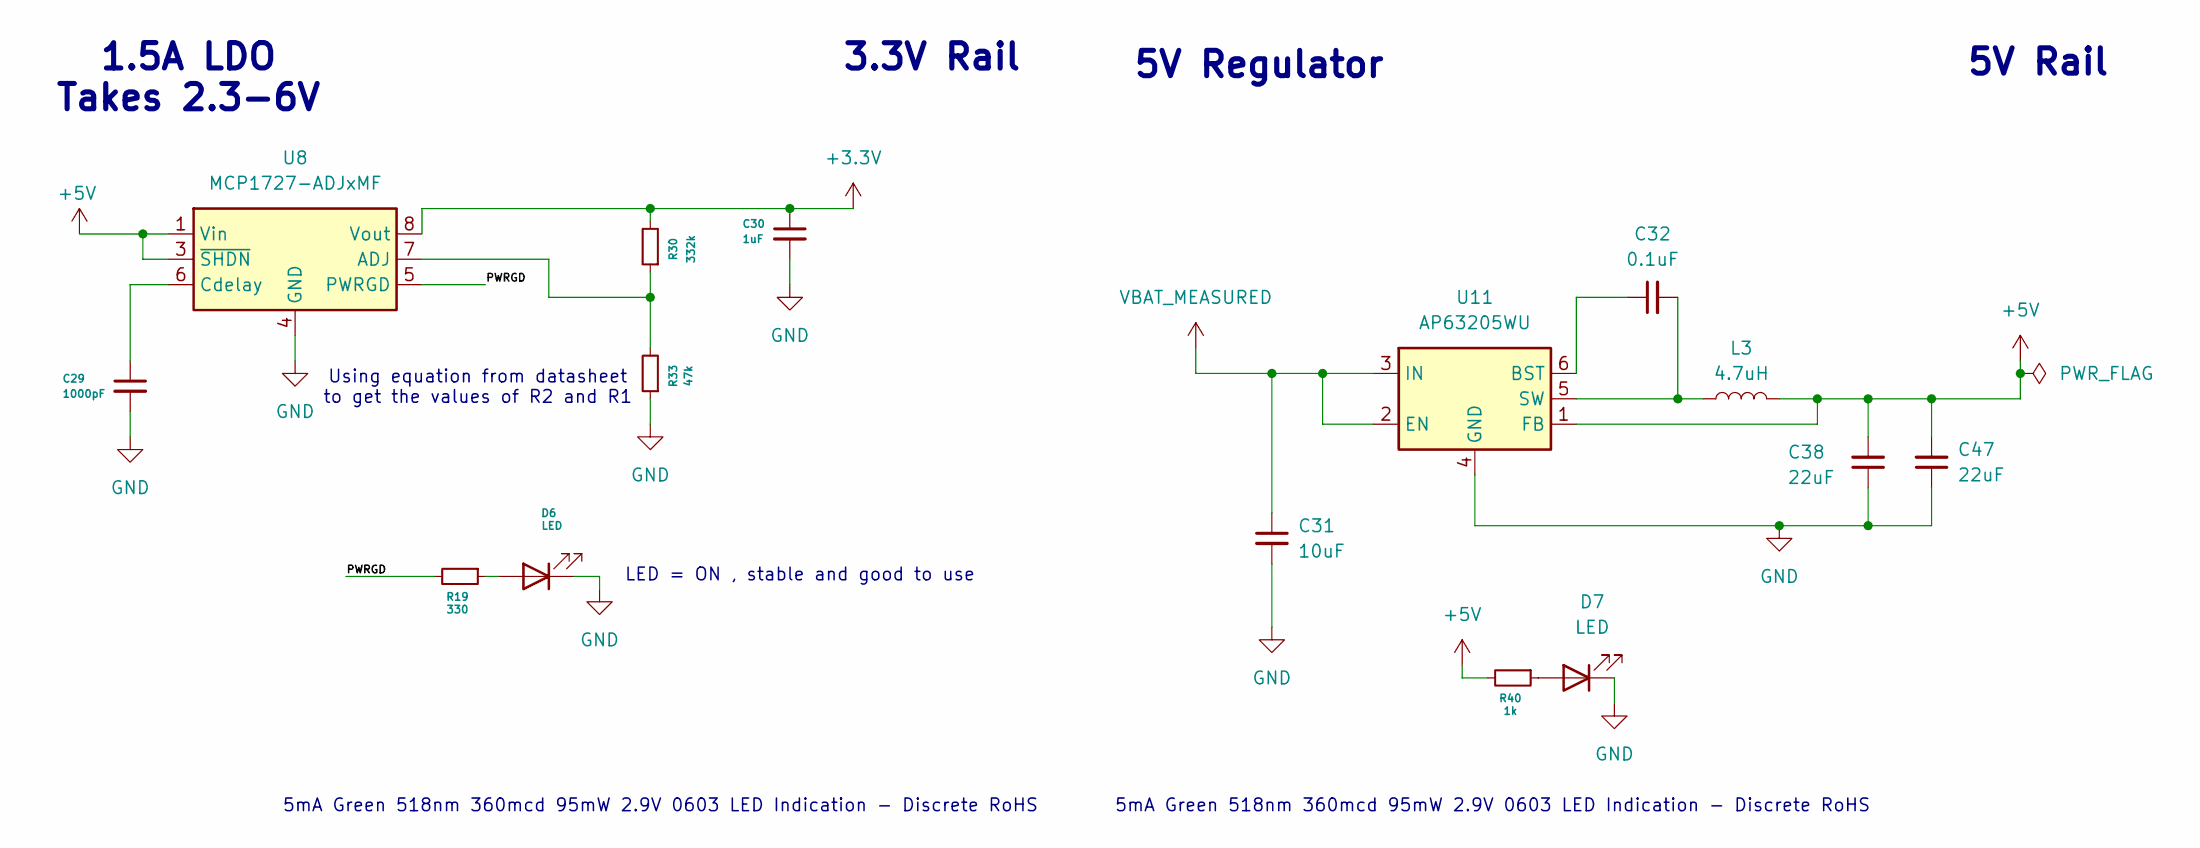
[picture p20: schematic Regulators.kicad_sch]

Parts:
C29: 1000pF; C_0805_2012Metric
C30: 1uF; C_0805_2012Metric
C31: 10uF; C_0805_2012Metric
C32: 0.1uF; C_0805_2012Metric
C38: 22uF; C_0805_2012Metric
C47: 22uF; C_0603_1608Metric
D6, D7: LED; LED_0603_1608Metric
L3: 4.7uH; L_Vishay_IFSC-1515AH_4x4x1.8mm
R19: 330; R_0402_1005Metric
R30: 332k; R_0402_1005Metric
R33: 47k; R_0402_1005Metric
R40: 1k; R_0805_2012Metric
U8: MCP1727-ADJxMF; DFN-8-1EP_3x3mm_P0.65mm_EP1.55x2.4mm
U11: AP63205WU; TSOT-23-6

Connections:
+3.3V: C30.1, R30.2, U8.8 (Vout); also elsewhere on the board
/Regulators/PWRGD: R19.2, U8.5 (PWRGD)
GND: C29.2, C30.2, C31.2, C38.1, C47.1, D6.1 (K), D7.1 (K), R33.1, U8.4 (GND), U8.9 (GND), U11.4 (GND); also elsewhere on the board
INA226_VS: C38.2, C47.2, L3.2, R40.2, U8.1 (Vin), U8.2 (Vin), U8.3 (~SHDN), U11.1 (FB); also elsewhere on the board
unnamed: D6.2 (A), R19.1
unnamed: D7.2 (A), R40.1
unnamed: R30.1, R33.2, U8.7 (ADJ)
unnamed: C29.1, U8.6 (Cdelay)
unnamed: C32.1, U11.6 (BST)
unnamed: C32.2, L3.1, U11.5 (SW)
VBAT_MEASURED: C31.1, U11.2 (EN), U11.3 (IN); also elsewhere on the board

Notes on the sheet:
1.5A LDO Takes 2.3-6V
5V Rail
LED = ON , stable and good to use
5mA Green 518nm 360mcd 95mW 2.9V 0603 LED Indication - Discrete RoHS
3.3V Rail
Using equation from datasheet to get the values of R2 and R1
5V Regulator

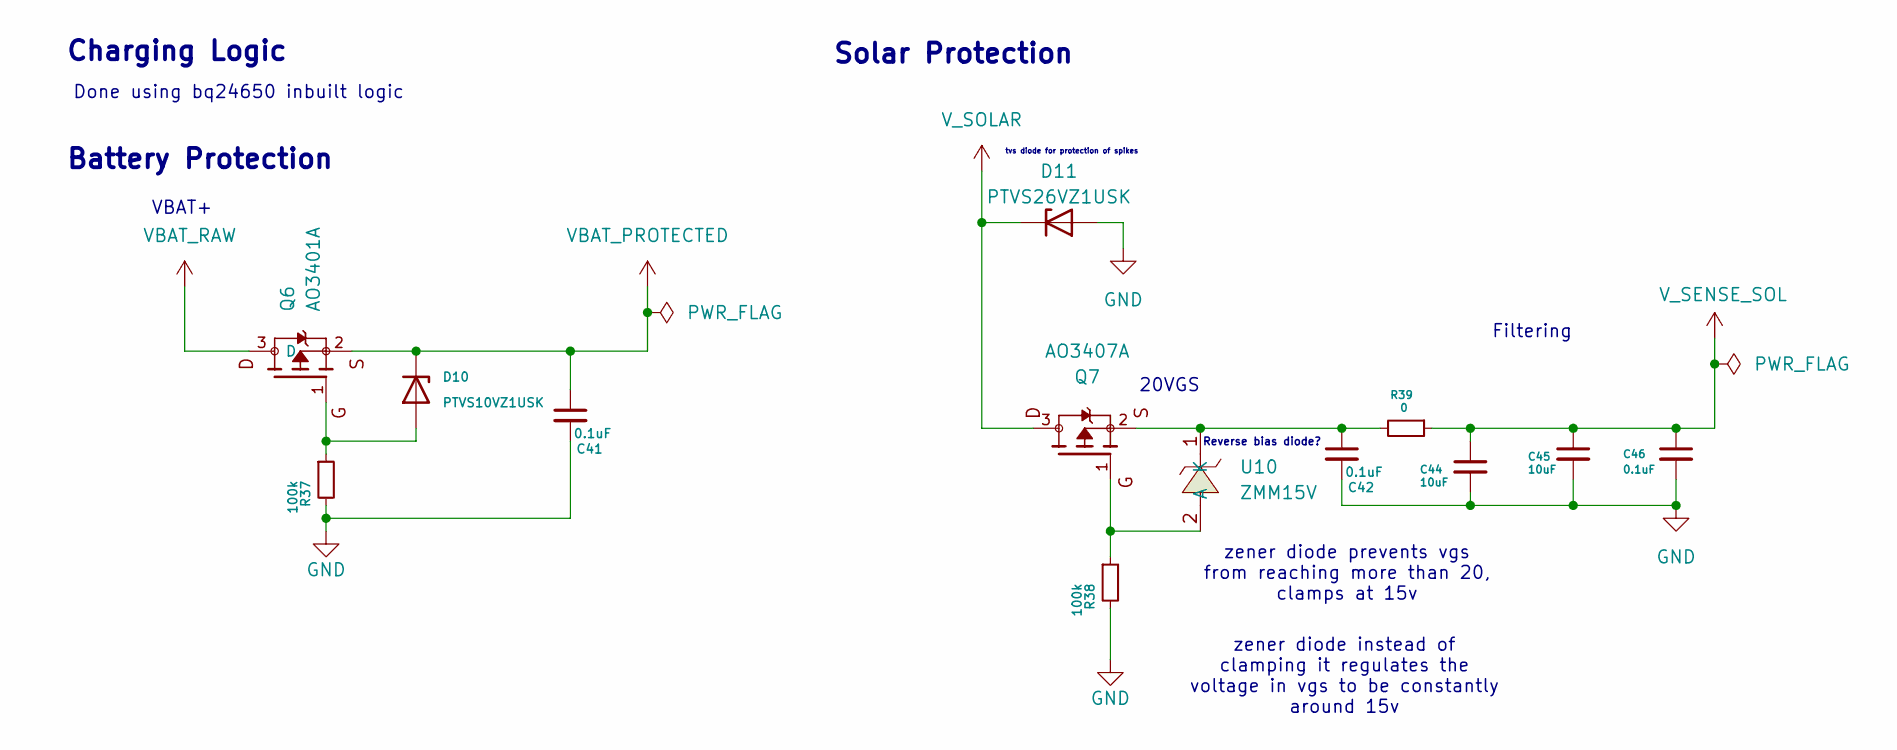
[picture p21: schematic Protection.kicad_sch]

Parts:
C41, C42, C46: 0.1uF; C_0603_1608Metric
C44, C45: 10uF; C_0805_2012Metric
D10: PTVS10VZ1USK; Nexperia_DSN1608-2_1.6x0.8mm
D11: PTVS26VZ1USK; Nexperia_DSN1608-2_1.6x0.8mm
Q6: AO3401A; SOT23-3
Q7: AO3407A; SOT95P280X125-3N; PARTREV 5
R37, R38: 100k; R_0805_2012Metric
R39: 0; R_0805_2012Metric
U10: ZMM15V; LL-34_L3.5-W1.5-RD; LCSC Part C5346000

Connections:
GND: C41.2, C42.2, C44.2, C45.2, C46.2, D11.2 (A), R37.2, R38.2; also elsewhere on the board
unnamed: D10.2 (A), Q6.1, R37.1
unnamed: Q7.1, R38.1, U10.2 (A)
unnamed: C42.1, Q7.2, R39.2, U10.1 (K)
VBAT_PROTECTED: C41.1, D10.1 (K), Q6.2; also elsewhere on the board
VBAT_RAW: Q6.3 (D); also elsewhere on the board
V_SENSE_SOL: C44.1, C45.1, C46.1, R39.1; also elsewhere on the board
V_SOLAR: D11.1 (K), Q7.3; also elsewhere on the board

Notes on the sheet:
Reverse bias diode?
20VGS
zener diode instead of clamping it regulates the voltage in vgs to be constantly around 15v
Done using bq24650 inbuilt logic
Charging Logic
Battery Protection
VBAT+
Filtering
zener diode prevents vgs from reaching more than 20, clamps at 15v
tvs diode for protection of spikes
Solar Protection

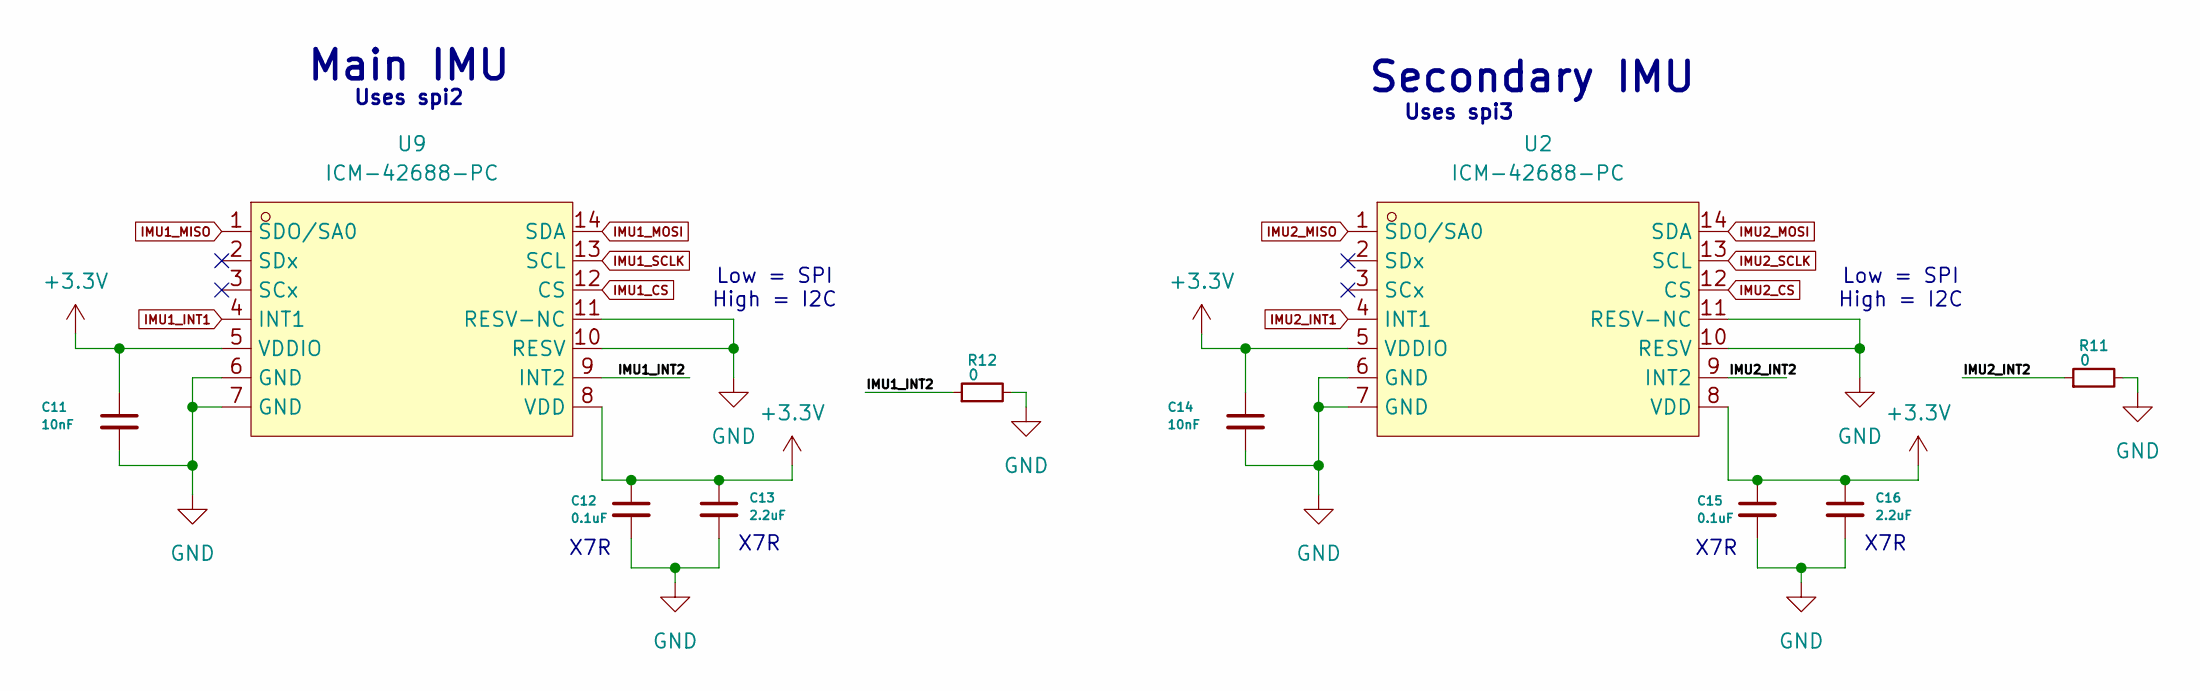
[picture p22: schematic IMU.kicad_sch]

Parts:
C11, C14: 10nF; C_0402_1005Metric
C12, C15: 0.1uF; C_0402_1005Metric
C13, C16: 2.2uF; C_0402_1005Metric
R11, R12: 0; R_0805_2012Metric
U2, U9: ICM-42688-PC; LGA-14_L3.0-W2.5-P0.50-TL; LCSC Part C48586483

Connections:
+3.3V: C11.1, C12.1, C13.1, C14.1, C15.1, C16.1, U2.5 (VDDIO), U2.8 (VDD), U9.5 (VDDIO), U9.8 (VDD); also elsewhere on the board
/IMU/IMU1_INT2: R12.1, U9.9 (INT2)
/IMU/IMU2_INT2: R11.1, U2.9 (INT2)
GND: C11.2, C12.2, C13.2, C14.2, C15.2, C16.2, R11.2, R12.2, U2.6 (GND), U2.7 (GND), U2.10 (RESV), U2.11 (RESV-NC), U9.6 (GND), U9.7 (GND), U9.10 (RESV), U9.11 (RESV-NC); also elsewhere on the board
IMU1_CS: U9.12 (CS); also elsewhere on the board
IMU1_INT1: U9.4 (INT1); also elsewhere on the board
IMU1_MISO: U9.1 (SDO/SA0); also elsewhere on the board
IMU1_MOSI: U9.14 (SDA); also elsewhere on the board
IMU1_SCLK: U9.13 (SCL); also elsewhere on the board
IMU2_CS: U2.12 (CS); also elsewhere on the board
IMU2_INT1: U2.4 (INT1); also elsewhere on the board
IMU2_MISO: U2.1 (SDO/SA0); also elsewhere on the board
IMU2_MOSI: U2.14 (SDA); also elsewhere on the board
IMU2_SCLK: U2.13 (SCL); also elsewhere on the board

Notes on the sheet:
Uses spi3
X7R
Low = SPI High = I2C
Uses spi2
Main IMU
Secondary IMU

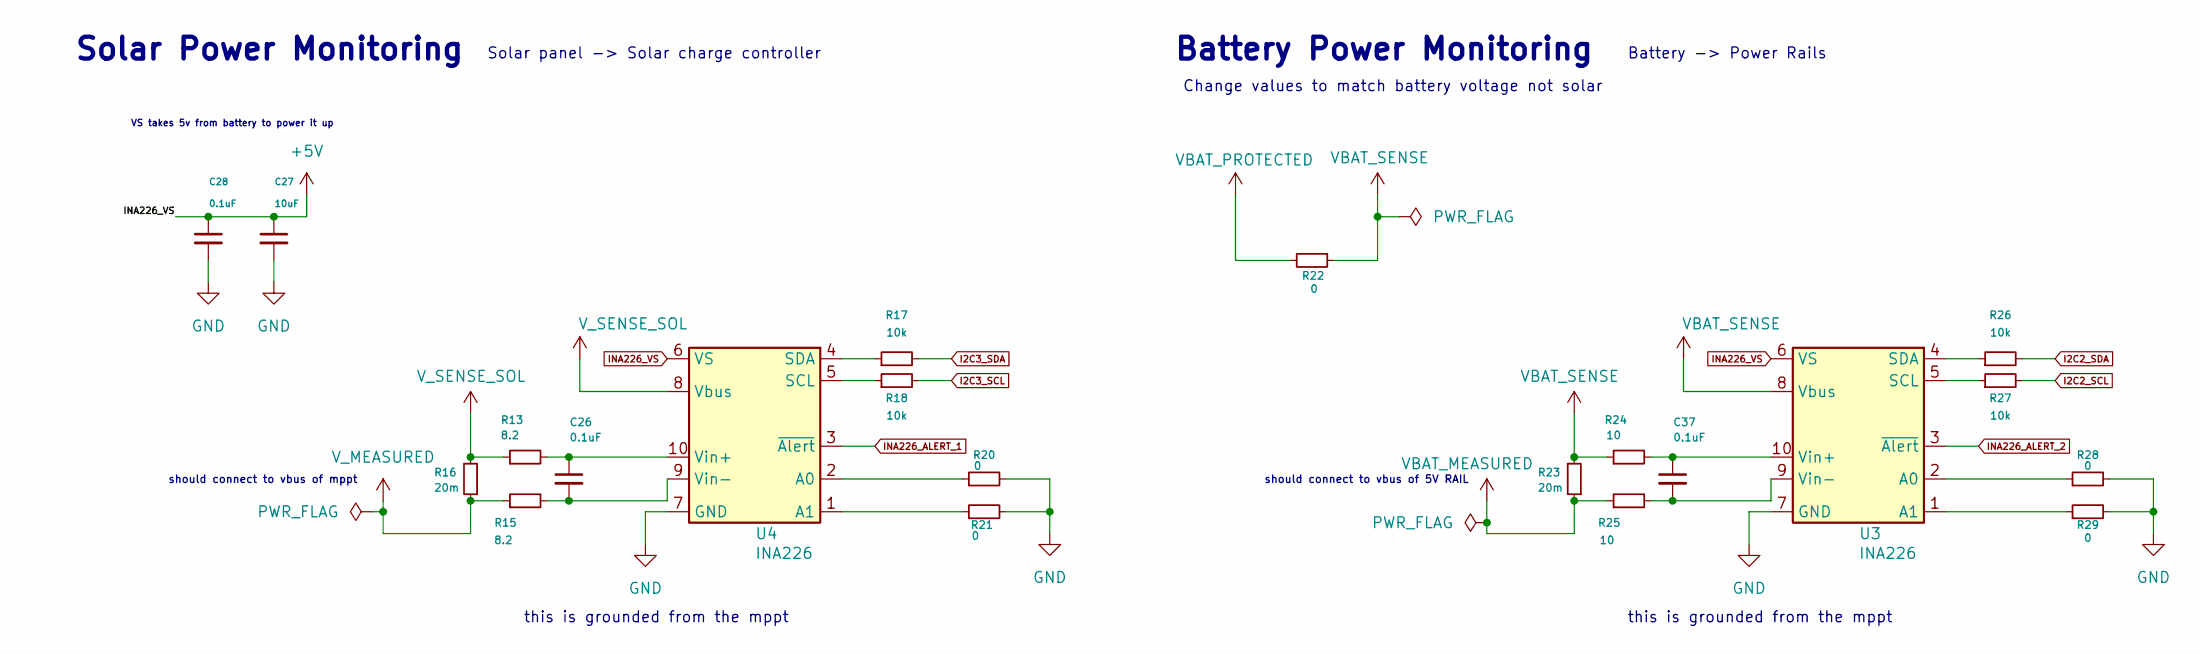
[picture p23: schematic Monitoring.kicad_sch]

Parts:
C26, C28, C37: 0.1uF; C_0603_1608Metric
C27: 10uF; C_0805_2012Metric
R13, R15: 8.2; R_0402_1005Metric
R16, R23: 20m; R_2512_6332Metric
R17, R18, R26, R27: 10k; R_0402_1005Metric
R20, R21, R22, R28, R29: 0; R_0805_2012Metric
R24, R25: 10; R_0603_1608Metric
U3, U4: INA226; VSSOP-10_3x3mm_P0.5mm

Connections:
GND: C27.2, C28.2, R20.2, R21.2, R28.2, R29.2, U3.7 (GND), U4.7 (GND); also elsewhere on the board
I2C2_SCL: R27.2; also elsewhere on the board
I2C2_SDA: R26.2; also elsewhere on the board
I2C3_SCL: R18.2; also elsewhere on the board
I2C3_SDA: R17.2; also elsewhere on the board
INA226_ALERT_1: U4.3 (~Alert); also elsewhere on the board
INA226_ALERT_2: U3.3 (~Alert); also elsewhere on the board
INA226_VS: C27.1, C28.1, U3.6 (VS), U4.6 (VS); also elsewhere on the board
unnamed: R28.1, U3.2 (A0)
unnamed: R29.1, U3.1 (A1)
unnamed: R27.1, U3.5 (SCL)
unnamed: R26.1, U3.4 (SDA)
unnamed: C37.1, R24.2, U3.10 (Vin+)
unnamed: C37.2, R25.2, U3.9 (Vin-)
unnamed: R20.1, U4.2 (A0)
unnamed: R21.1, U4.1 (A1)
unnamed: R18.1, U4.5 (SCL)
unnamed: R17.1, U4.4 (SDA)
unnamed: C26.1, R13.2, U4.10 (Vin+)
unnamed: C26.2, R15.2, U4.9 (Vin-)
VBAT_MEASURED: R23.1, R25.1; also elsewhere on the board
VBAT_PROTECTED: R22.2; also elsewhere on the board
VBAT_SENSE: R22.1, R23.2, R24.1, U3.8 (Vbus)
V_MEASURED: R15.1, R16.1; also elsewhere on the board
V_SENSE_SOL: R13.1, R16.2, U4.8 (Vbus); also elsewhere on the board

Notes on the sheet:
Solar panel -> Solar charge controller
Battery Power Monitoring
VS takes 5v from battery to power it up
this is grounded from the mppt
should connect to vbus of 5V RAIL
Battery -> Power Rails
Solar Power Monitoring
Change values to match battery voltage not solar
should connect to vbus of mppt

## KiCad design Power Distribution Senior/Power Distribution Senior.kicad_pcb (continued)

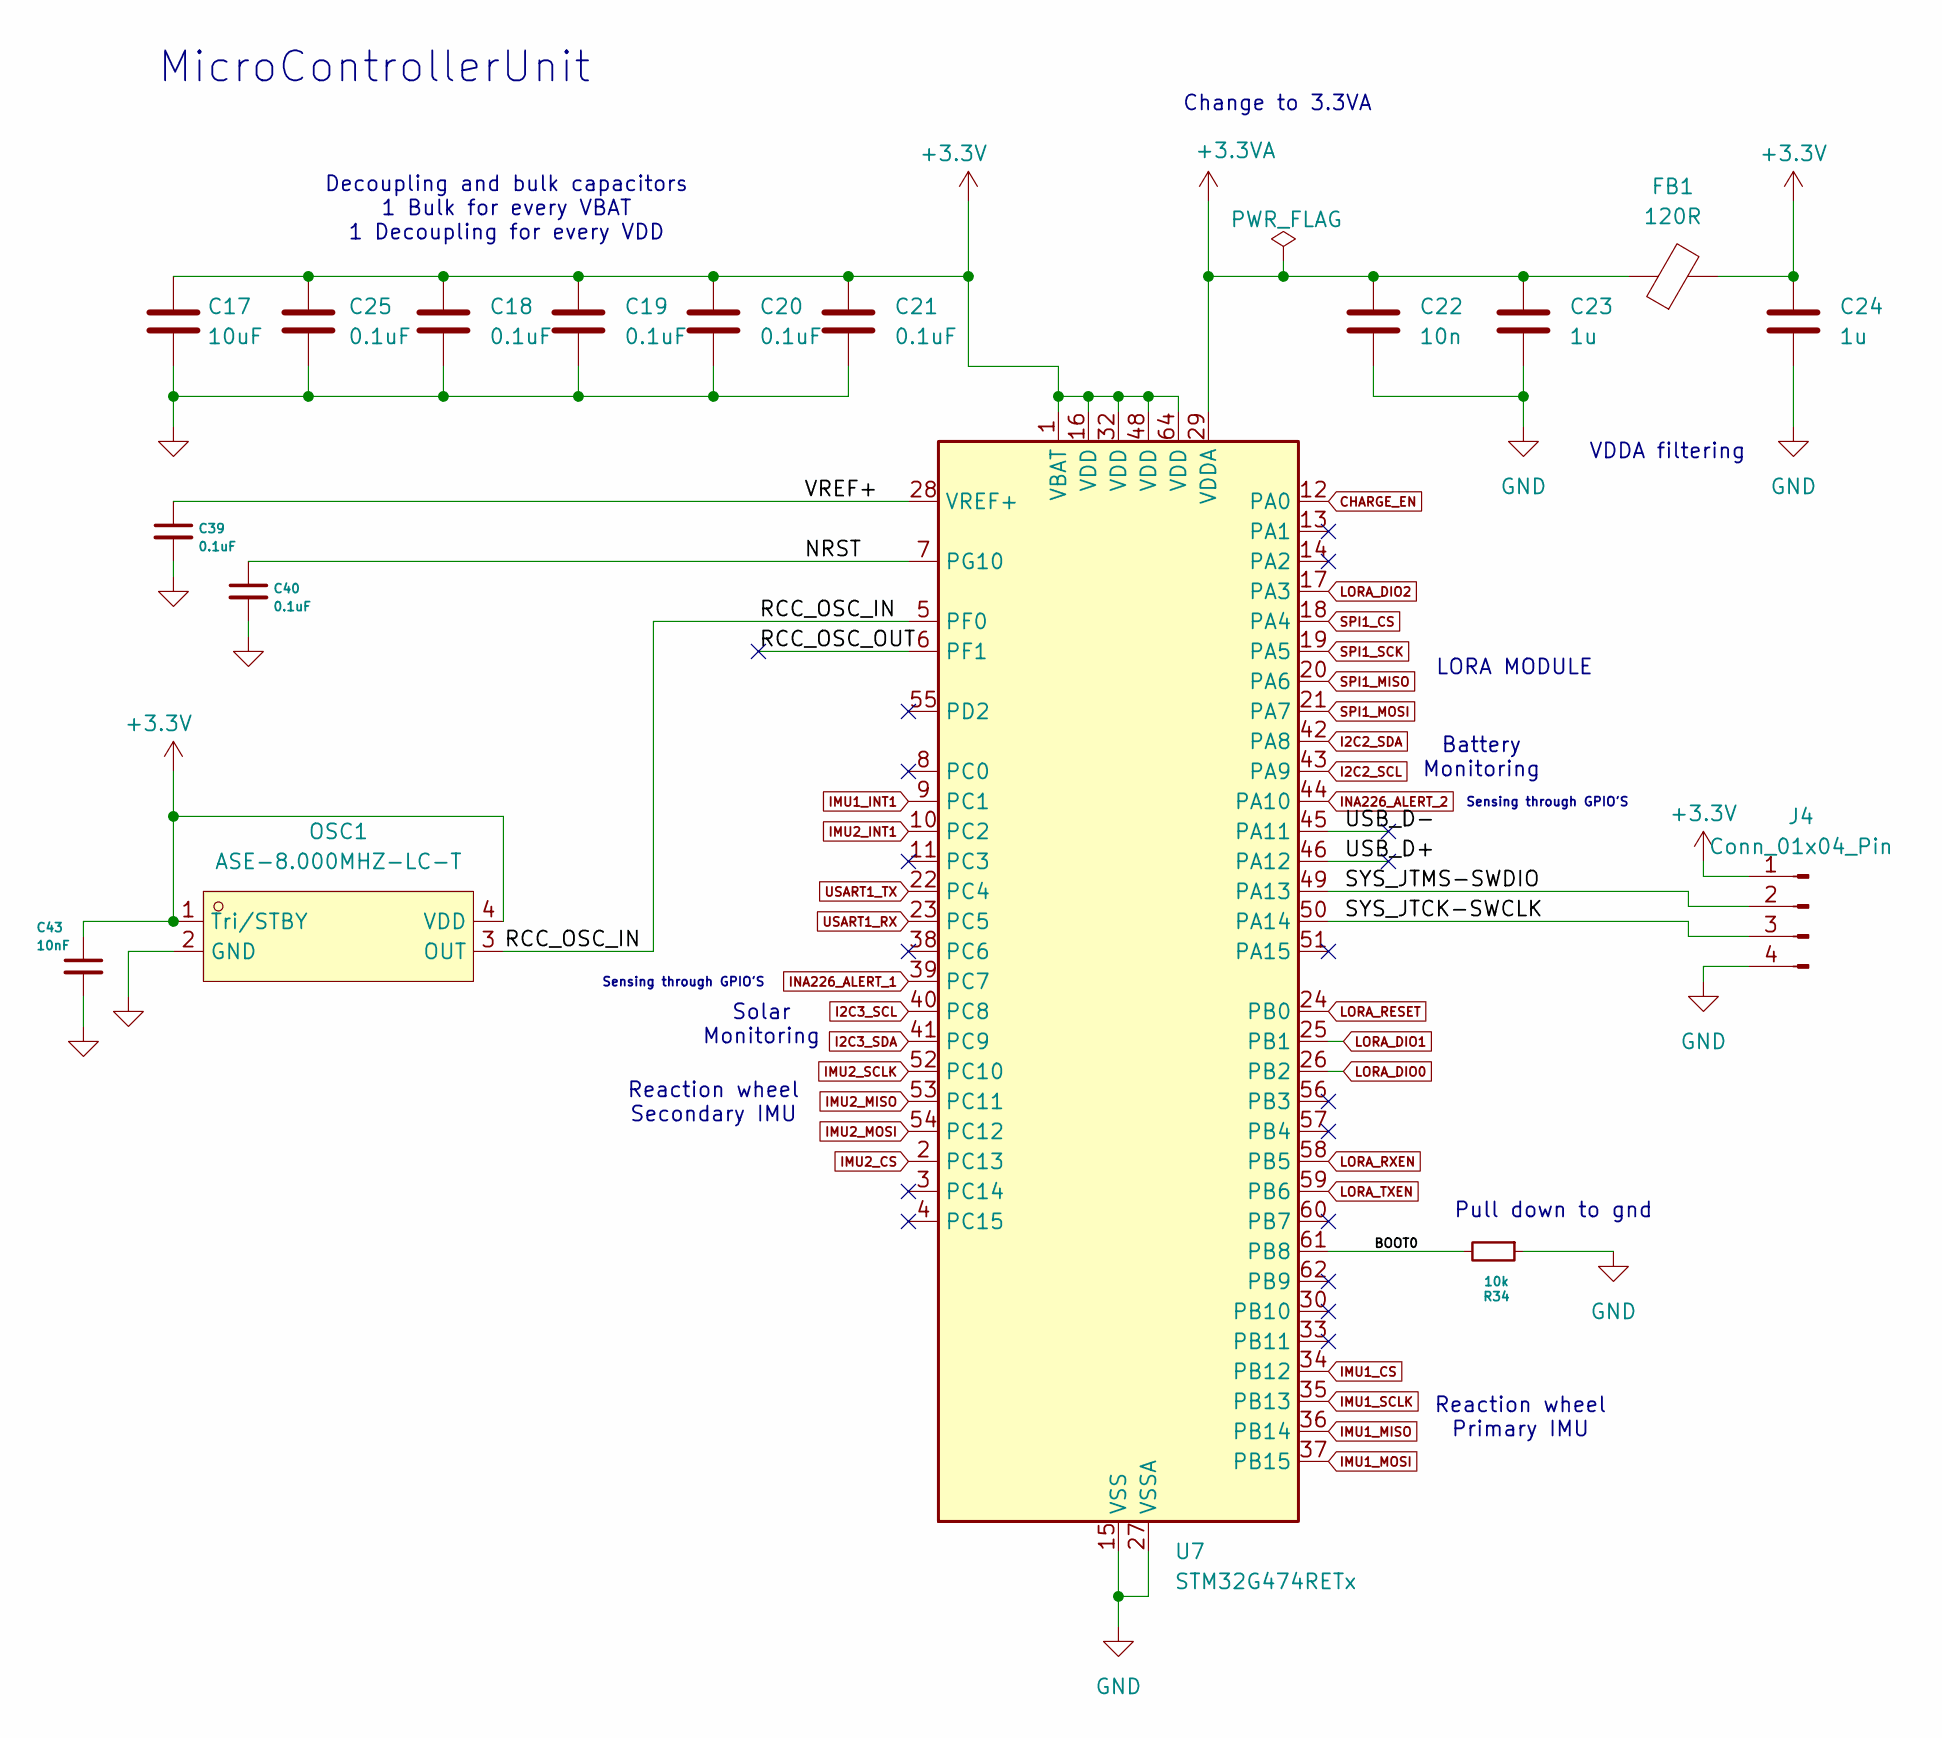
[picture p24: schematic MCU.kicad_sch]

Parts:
C17: 10uF; C_0805_2012Metric
C18, C19, C20, C21, C25: 0.1uF; C_0402_1005Metric
C22: 10n; C_0603_1608Metric
C23, C24: 1u; C_0603_1608Metric
C39, C40: 0.1uF; C_0603_1608Metric
C43: 10nF; C_0603_1608Metric
FB1: 120R; L_0603_1608Metric
J4: Conn_01x04_Pin; PinHeader_1x04_P2.54mm_Vertical
OSC1: ASE-8.000MHZ-LC-T; OSC-SMD_4P-L3.2-W2.5-CJ13-320001210A20; LCSC Part C6277872
R34: 10k; R_0402_1005Metric
U7: STM32G474RETx; LQFP-64_10x10mm_P0.5mm

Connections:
+3.3V: C17.1, C18.1, C19.1, C20.1, C21.1, C24.1, C25.1, C43.1, FB1.2, J4.1, OSC1.1 (Tri/STBY), OSC1.4 (VDD), U7.1 (VBAT), U7.16 (VDD), U7.32 (VDD), U7.48 (VDD), U7.64 (VDD); also elsewhere on the board
+3.3VA: C22.1, C23.1, FB1.1, U7.29 (VDDA)
/MCU/BOOT0: R34.2, U7.61 (PB8)
/MCU/NRST: C40.1, U7.7 (PG10)
/MCU/RCC_OSC_IN: OSC1.3 (OUT), U7.5 (PF0)
/MCU/RCC_OSC_OUT: U7.6 (PF1)
/MCU/SYS_JTCK-SWCLK: J4.3, U7.50 (PA14)
/MCU/SYS_JTMS-SWDIO: J4.2, U7.49 (PA13)
/MCU/USB_D+: U7.46 (PA12)
/MCU/USB_D-: U7.45 (PA11)
/MCU/VREF+: C39.1, U7.28 (VREF+)
CHARGE_EN: U7.12 (PA0); also elsewhere on the board
GND: C17.2, C18.2, C19.2, C20.2, C21.2, C22.2, C23.2, C24.2, C25.2, C39.2, C40.2, C43.2, J4.4, OSC1.2 (GND), R34.1, U7.15 (VSS), U7.27 (VSSA), U7.31 (VSS), U7.47 (VSS), U7.63 (VSS); also elsewhere on the board
I2C2_SCL: U7.43 (PA9); also elsewhere on the board
I2C2_SDA: U7.42 (PA8); also elsewhere on the board
I2C3_SCL: U7.40 (PC8); also elsewhere on the board
I2C3_SDA: U7.41 (PC9); also elsewhere on the board
IMU1_CS: U7.34 (PB12); also elsewhere on the board
IMU1_INT1: U7.9 (PC1); also elsewhere on the board
IMU1_MISO: U7.36 (PB14); also elsewhere on the board
IMU1_MOSI: U7.37 (PB15); also elsewhere on the board
IMU1_SCLK: U7.35 (PB13); also elsewhere on the board
IMU2_CS: U7.2 (PC13); also elsewhere on the board
IMU2_INT1: U7.10 (PC2); also elsewhere on the board
IMU2_MISO: U7.53 (PC11); also elsewhere on the board
IMU2_MOSI: U7.54 (PC12); also elsewhere on the board
IMU2_SCLK: U7.52 (PC10); also elsewhere on the board
INA226_ALERT_1: U7.39 (PC7); also elsewhere on the board
INA226_ALERT_2: U7.44 (PA10); also elsewhere on the board
LORA_DIO0: U7.26 (PB2); also elsewhere on the board
LORA_DIO1: U7.25 (PB1); also elsewhere on the board
LORA_DIO2: U7.17 (PA3); also elsewhere on the board
LORA_RESET: U7.24 (PB0); also elsewhere on the board
LORA_RXEN: U7.58 (PB5); also elsewhere on the board
LORA_TXEN: U7.59 (PB6); also elsewhere on the board
SPI1_CS: U7.18 (PA4); also elsewhere on the board
SPI1_MISO: U7.20 (PA6); also elsewhere on the board
SPI1_MOSI: U7.21 (PA7); also elsewhere on the board
SPI1_SCK: U7.19 (PA5); also elsewhere on the board
USART1_RX: U7.23 (PC5)
USART1_TX: U7.22 (PC4)

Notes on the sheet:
VDDA filtering
Pull down to gnd
Sensing through GPIO'S
Reaction wheel Primary IMU
LORA MODULE
MicroControllerUnit
Reaction wheel Secondary IMU
Battery Monitoring
Solar Monitoring
Change to 3.3VA
Decoupling and bulk capacitors 1 Bulk for every VBAT 1 Decoupling for every VDD

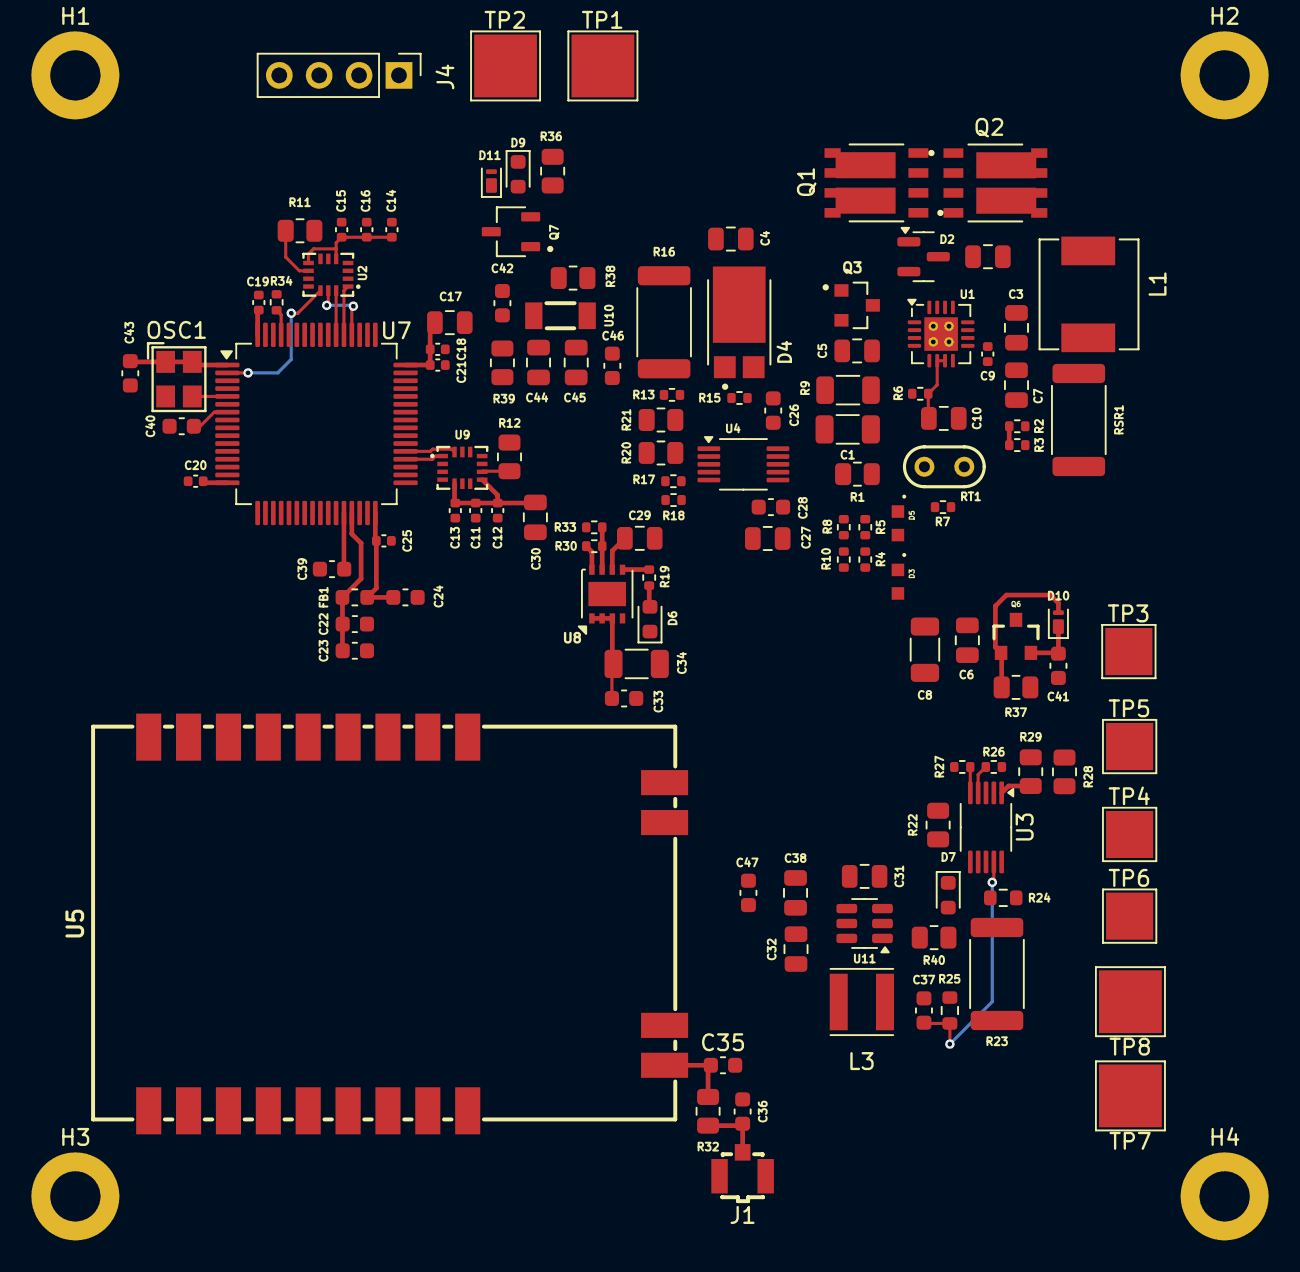
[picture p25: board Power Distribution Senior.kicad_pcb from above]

Board: 4 copper layers, 128 parts (0 on the bottom side), 88 nets.

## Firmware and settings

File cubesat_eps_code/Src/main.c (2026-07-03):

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
/* Includes ------------------------------------------------------------------*/
#include "main.h"

/* USER CODE BEGIN Includes */
#include <stdio.h>
#include "eps_ina226.h"
#include "eps_soc.h"
#include "eps_fsm.h"
#include "eps_gpio.h"
#include "eps_flash.h"
#include "eps_watchdog.h"
#include "eps_imu.h"
#include "LoRa.h"
#include <string.h>
/* USER CODE END Includes */

I2C_HandleTypeDef hi2c2;
I2C_HandleTypeDef hi2c3;

SPI_HandleTypeDef hspi1;
SPI_HandleTypeDef hspi2;

/* USER CODE BEGIN PV */
float g_vbat = 0.0f;
float g_vsol = 0.0f;
float g_ibat_mA = 0.0f;
uint8_t g_u3_ok = 0;
uint8_t g_u4_ok = 0;
uint32_t g_loop_count = 0;
int g_soc = 0;
uint8_t g_fsm_state = 0;
uint8_t g_charge_en = 0;
uint8_t g_boot_reason = 0;
uint8_t g_flash_save_result = 0xFF;
uint32_t g_flash_magic = 0;
uint8_t g_flash_state = 0xFF;
uint8_t g_flash_soc = 0xFF;
float g_flash_vbat = 0.0f;
uint32_t g_flash_crc_stored = 0;
uint32_t g_flash_crc_calc = 0;
uint8_t g_crc_ok = 0;
uint8_t g_wdg_reason = 0;
uint32_t g_loop_time_ms = 0;
uint32_t g_ina_time_ms  = 0;
char g_telem_buf[128];
uint32_t g_telem_packet_id = 0;
uint32_t g_telem_uptime = 0;
const char *g_telem_str = g_telem_buf;
float g_accel_x = 0.0f;
float g_accel_y = 0.0f;
float g_accel_z = 0.0f;
float g_gyro_x = 0.0f;
float g_gyro_y = 0.0f;
float g_gyro_z = 0.0f;
uint8_t g_imu1_ok   = 0;
uint8_t g_imu2_ok   = 0;
uint8_t g_imu_fault = 0;
uint8_t g_imu1_whoami = 0;
uint8_t g_imu2_whoami = 0;
uint8_t g_imu_at_68 = 0;
uint8_t g_imu_at_69 = 0;
uint8_t g_scan_found = 0;
uint8_t g_scan_addr = 0;
LoRa myLoRa;
uint8_t g_lora_ok = 0;
uint32_t g_lora_sent = 0;
uint16_t g_lora_init_result = 0;
uint8_t g_lora_version = 0;
uint8_t g_lora_tx_result = 0;
uint8_t g_lora_frmsb = 0;
uint8_t g_lora_frmid = 0;
uint8_t g_lora_frlsb = 0;
float g_pbat_mW = 0.0f;
/* USER CODE END PV */

void SystemClock_Config(void);
static void MX_GPIO_Init(void);
static void MX_I2C3_Init(void);
static void MX_I2C2_Init(void);
static void MX_SPI2_Init(void);
static void MX_SPI1_Init(void);
/**
  * @brief  The application entry point.
  * @retval int
  */
int main(void)
{

  /* MCU Configuration--------------------------------------------------------*/

  /* Reset of all peripherals, Initializes the Flash interface and the Systick. */
  HAL_Init();

  /* Configure the system clock */
  SystemClock_Config();

  /* Initialize all configured peripherals */
  MX_GPIO_Init();
  MX_I2C3_Init();
  MX_I2C2_Init();
  MX_SPI2_Init();
  MX_SPI1_Init();
  /* USER CODE BEGIN 2 */
  HAL_GPIO_WritePin(GPIOA, GPIO_PIN_4,  GPIO_PIN_SET);  /* LORA_CS  */
  HAL_GPIO_WritePin(GPIOB, GPIO_PIN_12, GPIO_PIN_SET);  /* IMU1_CS  */
  HAL_GPIO_WritePin(GPIOC, GPIO_PIN_13, GPIO_PIN_SET);  /* IMU2_CS  */
  HAL_GPIO_WritePin(GPIOA, GPIO_PIN_12, GPIO_PIN_SET);  /* CHARGE_EN */

  HAL_GPIO_WritePin(GPIOB, GPIO_PIN_6, GPIO_PIN_RESET);   /* TXEN HIGH */
  HAL_GPIO_WritePin(GPIOB, GPIO_PIN_5, GPIO_PIN_RESET);
  HAL_Delay(10);

  GPIO_Loads_Init();
  g_u3_ok = INA226_Check(1);
  if (g_u3_ok) INA226_Init(1);

  myLoRa = newLoRa();
  myLoRa.hSPIx = &hspi1;
  myLoRa.CS_port = GPIOA;
  myLoRa.CS_pin = GPIO_PIN_4;
  myLoRa.reset_port = GPIOB;
  myLoRa.reset_pin = GPIO_PIN_0;
  myLoRa.DIO0_port = GPIOB;
  myLoRa.DIO0_pin = GPIO_PIN_2;
  myLoRa.frequency = 433;
  myLoRa.spredingFactor = SF_7;
  myLoRa.bandWidth = BW_125KHz;
  myLoRa.crcRate = CR_4_5;
  myLoRa.power = POWER_20db;
  myLoRa.overCurrentProtection = 100;
  myLoRa.preamble = 8;
  //g_lora_ok = (LoRa_init(&myLoRa) == LORA_OK);
//  __HAL_RCC_SPI2_CLK_ENABLE();
  HAL_GPIO_WritePin(GPIOB, GPIO_PIN_0, GPIO_PIN_RESET);  /* RST LOW */
  HAL_Delay(10);
  HAL_GPIO_WritePin(GPIOB, GPIO_PIN_0, GPIO_PIN_SET);    /* RST HIGH */
  HAL_Delay(100);

  g_lora_version = LoRa_read(&myLoRa, 0x42);
//  uint8_t spi1_tx = 0x42;
//  uint8_t spi1_rx = 0x00;
//  HAL_StatusTypeDef spi1_status;

//  HAL_GPIO_WritePin(GPIOA, GPIO_PIN_4, GPIO_PIN_RESET);
//  spi1_status = HAL_SPI_TransmitReceive(&hspi1, &spi1_tx, &spi1_rx, 1, 100);
//  HAL_GPIO_WritePin(GPIOA, GPIO_PIN_4, GPIO_PIN_SET);

 // g_lora_version = spi1_rx;
//  g_imu1_whoami = (uint8_t)spi1_status;
  g_lora_init_result = LoRa_init(&myLoRa);
  g_lora_ok = (g_lora_init_result == LORA_OK);

  g_lora_frmsb = LoRa_read(&myLoRa, 0x06);
  g_lora_frmid = LoRa_read(&myLoRa, 0x07);
  g_lora_frlsb = LoRa_read(&myLoRa, 0x08);

  WDG_Init();
  g_wdg_reason = (uint8_t)WDG_GetLastResetReason();

//  g_imu1_ok = IMU_Check(1);
//  g_imu2_ok = IMU_Check(2);
//  if (g_imu1_ok) IMU_Init(1);
//  if (g_imu2_ok) IMU_Init(2);
 // g_imu1_whoami = IMU_ReadReg_Debug(1);
//  g_imu2_whoami = IMU_ReadReg_Debug(2);

//  HAL_StatusTypeDef spi_status = HAL_SPI_GetState(&hspi2);
//  g_imu1_whoami = IMU_ReadWhoAmI(1);
//  g_imu2_whoami = IMU_ReadWhoAmI(2);

//  g_imu1_ok = (g_imu1_whoami == 0x47) ? 1 : 0;
//  g_imu2_ok = (g_imu2_whoami == 0x47) ? 1 : 0;
//  if (g_imu1_ok) IMU_Init(1);
//  if (g_imu2_ok) IMU_Init(2);
//  g_i2c_scan[128] = {0};
//  for (uint8_t addr = 1; addr < 127; addr++)
//  {
//      if (HAL_I2C_IsDeviceReady(&hi2c2, addr << 1, 1, 10) == HAL_OK)
//          g_i2c_scan[addr] = 1;
//  }

//  g_scan_found = 0;
//  g_scan_addr = 0;
//  for (uint8_t addr = 1; addr < 127; addr++)
//  {
//      if (HAL_I2C_IsDeviceReady(&hi2c2, addr << 1, 1, 10) == HAL_OK)
//      {
//          g_scan_found++;
//          g_scan_addr = addr;  /* запомним последний найденный */
//      }
//  }

//  HAL_GPIO_WritePin(GPIOB, GPIO_PIN_12, GPIO_PIN_RESET);  /* CS LOW — IMU1 */
//  HAL_SPI_TransmitReceive(&hspi2, &spi_tx, &spi_rx, 1, 100);
//  HAL_GPIO_WritePin(GPIOB, GPIO_PIN_12, GPIO_PIN_SET);    /* CS HIGH */

//  g_imu1_whoami = spi_rx;
  /* USER CODE END 2 */

  /* Infinite loop */
  /* USER CODE BEGIN WHILE */
  while (1)
  {
	  WDG_Refresh();
	  uint32_t t_start = HAL_GetTick();
	    INA226_Data bat = INA226_Read(1);
//	    INA226_Data sol = INA226_Read(0);
//	    if (g_u4_ok) sol = INA226_Read(0);
	    uint32_t t_after_ina = HAL_GetTick();
	    g_vbat = bat.voltage_V;
//	    g_vsol = sol.voltage_V;
	    g_ibat_mA = bat.current_mA;
	    g_pbat_mW = g_vbat * g_ibat_mA;

	    FSM_Update(g_vbat, g_vsol);

	    snprintf(g_telem_buf, sizeof(g_telem_buf),
	        "$EPS,%03lu,%d%%,%.2fV,st=%d,chg=%d,wdg=%d",
			g_telem_packet_id,
	        g_soc,
	        g_vbat,
	        g_fsm_state,
	        g_charge_en,
	        g_wdg_reason);
	    g_telem_packet_id++;
	    g_telem_uptime = HAL_GetTick() / 1000;

	    IMU_System imu = IMU_Update();
	    g_accel_x = imu.imu1.accel_x;
	    g_accel_y = imu.imu1.accel_y;
	    g_accel_z = imu.imu1.accel_z;
	    g_gyro_x = imu.imu1.gyro_x;
	    g_gyro_y = imu.imu1.gyro_y;
	    g_gyro_z = imu.imu1.gyro_z;
	    g_imu_fault = imu.fault;

	    g_soc = FSM_GetSOC();
	    g_fsm_state = (uint8_t)FSM_GetState();
	    g_charge_en = GPIO_GetChargeState();
	    g_boot_reason = (uint8_t)EPS_GetBootReason();
//	    g_crc_ok = EPS_Flash_DiagCRC();
	    g_loop_count++;
	    WDG_Refresh();
	    HAL_Delay(500);
	    static uint32_t last_lora = 0;
	    if (HAL_GetTick() - last_lora > 5000)
	    {
	        HAL_GPIO_WritePin(GPIOB, GPIO_PIN_6, GPIO_PIN_SET);
	        HAL_GPIO_WritePin(GPIOB, GPIO_PIN_5, GPIO_PIN_RESET);
	        char buf[64];
	        snprintf(buf, sizeof(buf),
	                 "$EPS,%03lu,%d%%,%d.%02dV,%dmW,st=%s",
	                 g_lora_sent, g_soc,
	                 (int)g_vbat,
	                 (int)(g_vbat * 100) % 100,
	                 (int)g_pbat_mW,
	                 FSM_GetStateName());
	        g_lora_tx_result = LoRa_transmit(&myLoRa, (uint8_t*)buf, strlen(buf), 100);
	        g_lora_sent++;
	        last_lora = HAL_GetTick();
	    }
	    g_loop_time_ms = HAL_GetTick() - t_start;
	    g_ina_time_ms  = t_after_ina - t_start;
    /* USER CODE END WHILE */

    /* USER CODE BEGIN 3 */
  }
  /* USER CODE END 3 */
}

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


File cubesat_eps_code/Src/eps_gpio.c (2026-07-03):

/* ============================================================
 *  eps_gpio.c — CubeSat EPS load control
 *
 *  Step 4: Implement load profiles for each FSM state.
 * ============================================================ */

#include "eps_gpio.h"
#include <string.h>

#define LOAD_ON GPIO_PIN_RESET
#define LOAD_OFF GPIO_PIN_SET

#define CHARGE_ON GPIO_PIN_SET
#define CHARGE_OFF GPIO_PIN_RESET

static uint8_t s_ch1_on = 0;
static uint8_t s_ch2_on = 0;
static uint8_t s_charge_on = 0;

static void set_ch1(uint8_t on) { (void)on; }

static void set_ch2(uint8_t on) { (void)on; }

static void set_charge(uint8_t on)
{
    HAL_GPIO_WritePin(CHARGE_EN_PORT, CHARGE_EN_PIN,
                      on ? CHARGE_ON : CHARGE_OFF);
    s_charge_on = on;
}

void GPIO_Loads_Init(void)
{
    set_ch1(0);
    set_ch2(0);
    set_charge(0);
}

void EnableAllLoads(void)
{
    set_charge(1);
    set_ch1(1);
    set_ch2(1);
}

void EnableCriticalLoads(void)
{
    set_charge(1);
    set_ch1(1);
    set_ch2(0);
}

void DisableNonEssential(void)
{
    set_charge(1);
    set_ch1(0);
    set_ch2(0);
}

void DisableAllLoads(void)
{
    set_ch1(0);
    set_ch2(0);
    set_charge(0);
}

void ChargeEnable(void) { set_charge(1); }
void ChargeDisable(void) { set_charge(0); }

uint8_t GPIO_GetLoadCh1State(void) { return s_ch1_on; }
uint8_t GPIO_GetLoadCh2State(void) { return s_ch2_on; }
uint8_t GPIO_GetChargeState(void) { return s_charge_on; }

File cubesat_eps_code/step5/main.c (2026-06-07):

#include "main.h"
#include "eps_soc.h"
#include "eps_fsm.h"
#include "eps_gpio.h"
#include "eps_flash.h"
#include <stdio.h>
#include <string.h>

ADC_HandleTypeDef  hadc;
UART_HandleTypeDef huart1;

#define R_TOP 100000.0f
#define R_BOT 47000.0f
#define V_REF 3.3f
#define ADC_MAX 4095.0f
#define DIVIDER_FACTOR ((R_TOP + R_BOT) / R_BOT)
#define ADC_SAMPLES 16
#define ADC_CH_VBAT ADC_CHANNEL_0 
#define ADC_CH_VSOL ADC_CHANNEL_1

void SystemClock_Config(void);
void MX_GPIO_Init(void);
void MX_ADC_Init(void);
void MX_USART1_UART_Init(void);

static float Read_Voltage(uint32_t adc_channel)
{
    ADC_ChannelConfTypeDef config = {0};
    config.Channel = adc_channel;
    config.Rank = ADC_REGULAR_RANK_1;
    config.SamplingTime = ADC_SAMPLETIME_39CYCLES_5;
    HAL_ADC_ConfigChannel(&hadc, &config);

    uint32_t sum = 0;
    for (int i = 0; i < ADC_SAMPLES; i++)
    {
        HAL_ADC_Start(&hadc);
        HAL_ADC_PollForConversion(&hadc, 10);
        sum += HAL_ADC_GetValue(&hadc);
        HAL_ADC_Stop(&hadc);
        HAL_Delay(2);
    }
    float v_adc = ((float)sum / ADC_SAMPLES) * V_REF / ADC_MAX;
    return v_adc * DIVIDER_FACTOR;
}

static void UART_Print(const char *str)
{
    HAL_UART_Transmit(&huart1, (uint8_t *)str,
                      (uint16_t)strlen(str), 100);
}

static const char *BootReasonName(void)
{
    switch (EPS_GetBootReason())
    {
        case BOOT_REASON_COLD:
        return "COLD";
        case BOOT_REASON_HIBERNATE:
        return "HIBERNATE";
        case BOOT_REASON_CORRUPT_LOG:
        return "CORRUPT_LOG";
        default: return "UNKNOWN";
    }
}

int main(void)
{
    HAL_Init();
    SystemClock_Config();
    MX_GPIO_Init();
    MX_ADC_Init();
    MX_USART1_UART_Init();
    GPIO_Loads_Init();

    UART_Print("\r\n=== CubeSat EPS — Step 5: GPIO + Flash ===\r\n");
    char buf[96];
    uint32_t counter = 0;
    EPS_State prev_state = STATE_COUNT;

    while (1)
    {
INA226_Data bat = INA226_Read_OnBus(&hi2c2, INA226_ADDR_U3);
INA226_Data sol = INA226_Read_OnBus(&hi2c3, INA226_ADDR_U4);
float vbat = bat.voltage_V;
float vsol = sol.voltage_V;

        FSM_Update(vbat, vsol);

        EPS_State state = FSM_GetState();
        int soc = FSM_GetSOC();
        const char *name = FSM_GetStateName();
        if (state != prev_state)
        {
            snprintf(buf, sizeof(buf),
                     "\r\n>>> [%s] boot=%s ch1=%d ch2=%d chg=%d\r\n\r\n",
                     name,
                     BootReasonName(),
                     GPIO_GetLoadCh1State(),
                     GPIO_GetLoadCh2State(),
                     GPIO_GetChargeState());
            UART_Print(buf);
            prev_state = state;
        }
        snprintf(buf, sizeof(buf),
                 "[%04lu] %.3fV %3d%% Vsol=%.3fV %-10s "
                 "ch1=%d ch2=%d chg=%d boot=%s\r\n",
                 counter++, vbat, soc, vsol, name,
                 GPIO_GetLoadCh1State(),
                 GPIO_GetLoadCh2State(),
                 GPIO_GetChargeState(),
                 BootReasonName());
        UART_Print(buf);

        HAL_Delay(500);
    }
}

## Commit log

2025-12-12 This commit Adds the Hardware folder
    [MCU.kicad_sch, Power Distribution Senior.kicad_pcb, Power Distribution Senior.kicad_sch]
2025-12-16 Added FootPrints
    [MCU.kicad_sch, Power Distribution Senior.kicad_sch]
2026-04-01 Updated pcb
    [IMU.kicad_sch, MCU.kicad_sch, Monitoring.kicad_sch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]

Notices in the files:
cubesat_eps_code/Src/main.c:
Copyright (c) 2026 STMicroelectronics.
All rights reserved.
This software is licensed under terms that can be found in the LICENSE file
